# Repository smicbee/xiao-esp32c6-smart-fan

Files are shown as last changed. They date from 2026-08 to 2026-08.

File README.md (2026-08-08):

# XIAO ESP32C6 Smart Fan





A hardware-verified retrofit that turns a simple three-speed rechargeable desk fan into a Wi-Fi/Home Assistant device **without replacing its original motor, charger, protection circuit, or buttons**.

The controller emulates the original active-low Power and Speed buttons, measures the real motor rail to identify Off/Stage 1/Stage 2/Stage 3, and converges from the freshly measured physical state to the latest requested state. Rapid commands are serialized by a generation-based worker instead of trusting delayed UI state.

> **German documentation:** [docs/README.de.md](docs/README.de.md)

> **Status:** Working prototype · hardware-specific · not certified. Recalibrate and electrically verify every different fan/controller revision before enabling button outputs.

<p align="center">
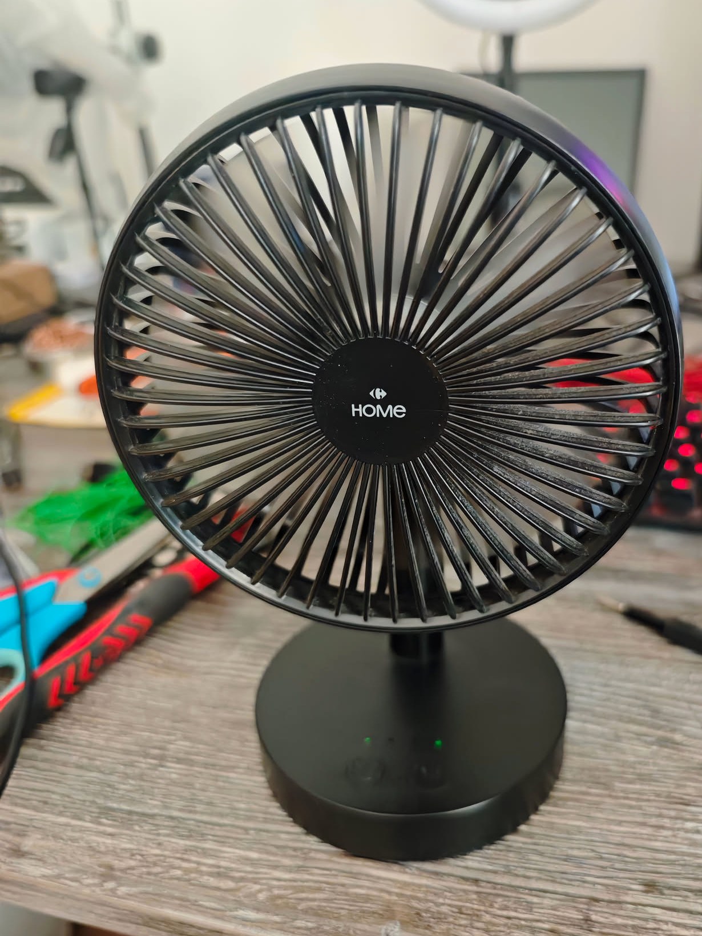
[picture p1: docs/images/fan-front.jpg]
Modified rechargeable desk fan
  
</p>

## What it can do

- Native encrypted ESPHome API and OTA updates over Wi-Fi.
- Home Assistant `fan` entity with three speeds.
- Original Power and Speed buttons remain functional.
- Active-low, 50 ms, open-drain button emulation; outputs are released afterward.
- Direct stage targeting without routinely power-cycling the fan:
  - Off → target: one Power pulse, then only the required Speed pulses.
  - Stage X → Stage Y: only the forward cyclic Speed pulses.
  - Running → Off: one Power pulse.
- Fresh motor-voltage sample before every controller pass; no dependency on delayed Home Assistant display state.
- Generation-based latest-target worker for sub-second command bursts.
- Stable motor-stage telemetry with median filtering, hysteresis, and five-sample confirmation.
- State-only feedback reconciliation: measured state can update Home Assistant but cannot generate a button pulse.
- Battery voltage and voltage-based state-of-charge estimate.
- Low-voltage protection: three readings below 3.05 V, deep sleep, 60 s wake checks, normal boot above 3.35 V.
- BMP280 temperature and pressure telemetry over SPI.
- Structured request/worker/ADC/GPIO/feedback logs plus reset reason, heap and maximum-loop-time diagnostics.

## Hardware

<p align="center">
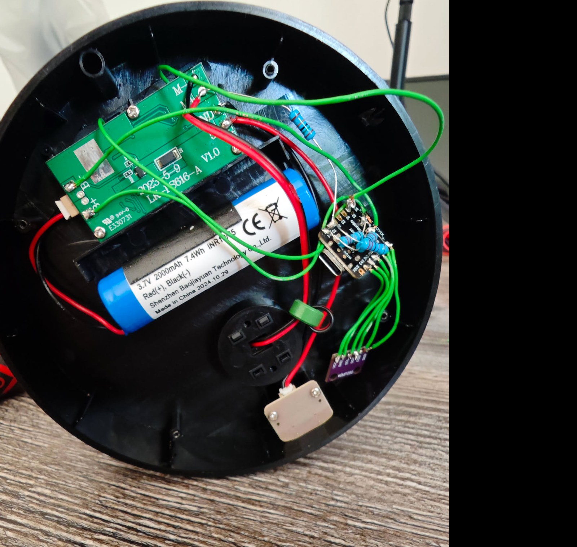
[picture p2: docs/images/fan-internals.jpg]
Fan internals and retrofit wiring
  
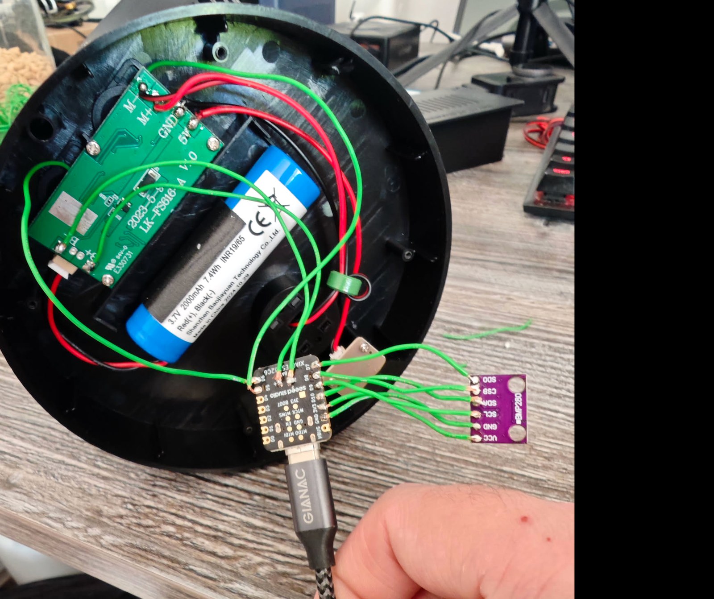
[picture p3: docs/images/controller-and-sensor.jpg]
XIAO ESP32C6 and BMP280 wiring
  
</p>

The prototype uses:

- Seeed Studio XIAO ESP32C6 (ESP32-C6FH4)
- BMP280 breakout (SPI)
- 150 kΩ + 22 kΩ motor-feedback divider
- 220 kΩ + 220 kΩ battery divider
- verified common ground between fan electronics and XIAO
- original 1-cell battery, motor controller, charger and protection electronics

See [hardware/BOM.csv](hardware/BOM.csv) and [docs/wiring.md](docs/wiring.md).

### Electrical schematic

XIAO ESP32C6 smart fan electrical schematic

The [editable KiCad 9 source](hardware/xiao-esp32c6-smart-fan.kicad_sch) shows the verified prototype topology: the XIAO only emulates the original Power/Speed buttons and measures divided-down voltages. It does not drive the motor directly and is not powered from the fan battery in the documented USB-powered prototype.

## Pin map

| XIAO pin | ESP32-C6 GPIO | Function |
|---|---:|---|
| D0 / A0 | GPIO0 | Battery ADC through 220 kΩ / 220 kΩ divider |
| D1 / A1 | GPIO1 | Motor rail ADC through 150 kΩ / 22 kΩ divider |
| D5 | GPIO23 | Original Speed button input, active-low/open-drain |
| D6 | GPIO16 | Original Power button input, active-low/open-drain |
| D7 | GPIO17 | BMP280 MISO / SDO |
| D8 | GPIO19 | BMP280 CSB |
| D9 | GPIO20 | BMP280 SCK / SCL |
| D10 | GPIO18 | BMP280 MOSI / SDA |
| 3V3 | — | BMP280 supply |
| GND | — | Common ground |

## Measured motor-voltage clusters

These values belong to the documented prototype and **must be recalibrated for another fan/controller**.

| Physical state | Reconstructed motor rail |
|---|---:|
| Off, no charger in one test | ~3.565 V |
| Off, USB charging | 4.636–4.683 V |
| Stage 1 | 4.941–4.980 V |
| Stage 2 | 6.513–6.536 V |
| Stage 3 | 7.912–7.960 V |

The charging Off cluster and Stage 1 are only about 0.27 V apart. The firmware therefore uses a midpoint for initial classification, Schmitt thresholds for subsequent transitions, ADC multisampling, median filtering and five stable samples. See [docs/calibration.md](docs/calibration.md).

## Control architecture

Controller architecture

Home Assistant supplies intent; the XIAO owns all GPIO actions:

1. `on_state` and `on_speed_set` store `requested_on`, `requested_stage` and increment `request_generation`.
2. A 250 ms dispatcher starts one single-owner worker if a generation is pending.
3. The worker force-updates the motor ADC and classifies the immediate 16-sample average.
4. It executes the minimum bounded pulse sequence from measured stage to requested stage.
5. It marks only the generation captured at worker start as handled. A newer request remains pending and gets another fresh physical read.
6. Slow filtered feedback later becomes authoritative for Home Assistant reconciliation, without touching the button outputs.

This design avoids the common `mode: restart` failure where a new request cancels a sequence after a physical pulse, and avoids relying on stale filtered/UI state.

## Quick start

### 1. Inspect and measure first

Do not assume another fan uses safe 3.3 V button signals or a ground-referenced motor rail.

- Disconnect power and identify Power, Speed, BAT+, BAT−, Motor+ and Motor−.
- Verify button-pad idle/pressed voltages and common ground with a multimeter.
- Confirm the selected motor low side remains at common ground in all states.
- Size dividers for the maximum credible voltage plus transient margin.
- First deploy voltage telemetry only and measure every state, both with and without charging.

### 2. Configure ESPHome secrets

```bash
cp esphome/secrets.example.yaml esphome/secrets.yaml
# edit esphome/secrets.yaml with your own values
```

### 3. Validate and commission over USB

```bash
python3.12 -m venv .venv
. .venv/bin/activate
pip install "esphome==2026.7.4"
esphome config esphome/ventilator-controller.yaml
esphome run esphome/ventilator-controller.yaml
```

The recommended workflow is **USB once, Wi-Fi/API/OTA immediately**. After the first successful boot and encrypted API verification, build and upload directly over the network:

```bash
esphome run esphome/ventilator-controller.yaml --device xiao-esp32c6-smart-fan.local
```

### 4. Add it to Home Assistant

ESPHome discovery normally offers the device automatically. Enter the API encryption key from your local `secrets.yaml`. Use the native three-speed fan entity; no custom stage buttons are required. See [docs/home-assistant.md](docs/home-assistant.md).

## Verified prototype behavior

Real hardware tests included:

- individual `3 → 1`, `1 → 2`, `2 → 3`, and final Off transitions;
- rapid `Stage 1 → Stage 3 → Off` requests within 0.99 s, ending physically Off;
- rapid `Off → Stage 1 → Stage 2 → Stage 3` requests within 1.08 s, ending physically at Stage 3 (~7.92 V);
- feedback reconciliation from the original hardware button;
- USB charging while distinguishing Off from Stage 1;
- encrypted Native API and OTA reconnect;
- firmware 1.5.6 diagnostic logging on real `Off → Stage 1 → Off` transitions;
- safe final state after tests.

The exact evidence boundary—including which firmware was exercised on hardware and which checks remain open—is documented in [docs/testing.md](docs/testing.md).

## Photos

<p align="center">
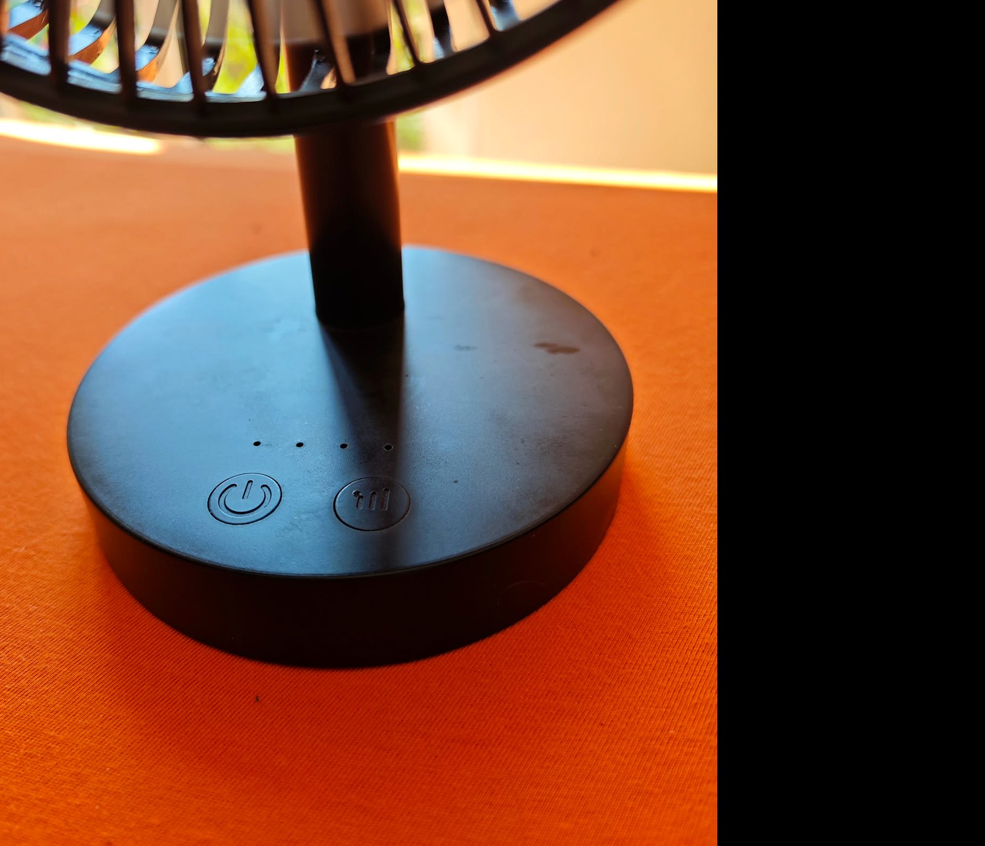
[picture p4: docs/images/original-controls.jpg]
Original power and speed controls
  
  Opened fan base
</p>

## Safety and limitations

- Modifying a Li-ion-powered appliance can cause fire, electric shock, battery damage or controller failure.
- Treat flashing, rebooting, restored state and Home Assistant commands as possible motor-start events during commissioning. Keep hands and loose objects clear and disconnect the motor while validating an unknown interface where practical.
- The XIAO is **not** the battery charger or BMS. The original electronics remain responsible for charging and protection.
- The photographed prototype was powered/programmed through USB during development. Do not connect the cell directly to XIAO 3V3/5V.
- Never connect Motor+ directly to an ADC pin.
- Direct GPIO button emulation is appropriate only after proving compatible voltage levels and common ground. Otherwise use a transistor, MOSFET or optocoupler interface.
- Motor outputs may be PWM even when a multimeter shows a stable average.
- Voltage-derived battery percentage is an estimate affected by load, chemistry, temperature and calibration.
- The narrow charging-Off/Stage-1 gap may not remain valid with another charger, cable, battery or fan revision.
- The low-voltage thresholds supplement; they do not replace the cell protection circuit.
- Keep the ESPHome API and OTA service on a trusted local network or VPN; do not expose ports 6053/3232 directly to the Internet.

## Repository layout

```text
esphome/                 ESPHome firmware and secrets template
hardware/                BOM / parts list
docs/diagrams/           public wiring and architecture drawings
docs/                    wiring, calibration, HA setup and German documentation
docs/images/             project photographs
tools/                   optional serial bring-up helper
.github/workflows/       ESPHome validation/compile CI
```

## License

Software, diagrams and documentation are released under the [MIT License](LICENSE). Product names and trademarks belong to their respective owners.

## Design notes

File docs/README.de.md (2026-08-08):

# XIAO ESP32C6 Smart Fan – deutsche Projektdokumentation

Dieses Projekt rüstet einen einfachen dreistufigen Akku-Tischventilator mit WLAN und Home Assistant nach. Die originale Motorsteuerung, Ladeelektronik, Zellschutzschaltung und die beiden Taster bleiben erhalten. Ein Seeed Studio XIAO ESP32C6 emuliert nur die aktiven Low-Taster und misst zusätzlich Motor- und Akkuspannung.

Umgebauter Ventilator

## Funktionsumfang

- verschlüsselte ESPHome Native API und OTA
- native dreistufige Home-Assistant-Fan-Entity
- weiterhin nutzbare Originaltaster
- 50-ms-Impulse auf Power und Speed, anschließend elektrische Freigabe
- gezielte Stufenwechsel ohne routinemäßiges Aus-/Ein-Reset
- echte Stufenerkennung über Motor+ und Spannungsteiler an D1/GPIO1
- frische Istmessung vor jedem Controllerdurchlauf
- generationenbasierter Worker für schnelle Folgebefehle
- hardwarebasierte, impulsfreie Korrektur der HA-Anzeige
- BMP280 für Temperatur und Luftdruck
- Akkuspannung und geschätzter Ladezustand
- Unterspannungs-Deep-Sleep mit 60-s-Prüfintervall

## Wesentliche Architekturentscheidung

Home Assistant ist nur Sollwertgeber. Der Home-Assistant-Anzeigestand wird niemals als physischer Istzustand verwendet. Jede noch offene Sollanforderung führt zu einem neuen D1-ADC-Snapshot. Daraus berechnet der XIAO die minimale Aktion:

- **Aus → Zielstufe:** Power-Impuls, dann nötige Speed-Impulse
- **Stufe X → Stufe Y:** nur zyklisch nötige Speed-Impulse
- **Laufend → Aus:** genau ein Power-Impuls

Während eines 50-ms-Impulses besitzt genau ein Worker die Ausgänge. Neue Befehle erhöhen eine Generation und bleiben offen. Nach Abschluss erfolgt eine neue Istmessung für den neuesten Sollwert. Die langsame gefilterte Rückmeldung darf Home Assistant aktualisieren, aber niemals selbst einen Tasterimpuls auslösen.

## Hardware und Verdrahtung

Siehe [wiring.md](wiring.md) und [../hardware/BOM.csv](../hardware/BOM.csv).

Verdrahtungsplan

### Spannungsteiler

Motorfeedback:

```text
Motor+ ── 150 kΩ ──┬── D1 / GPIO1
                    │
                   22 kΩ
                    │
GND / Motor− ───────┴── GND
```

Akkumessung:

```text
BAT+ ── 220 kΩ ──┬── D0 / GPIO0
                  │
                 220 kΩ
                  │
BAT− / GND ───────┴── GND
```

Die Motor-Rückrechnung verwendet `(150k + 22k) / 22k ≈ 7,818`. Motor+ darf niemals direkt mit D1 verbunden werden.

## Gemessene Spannungen

| Zustand | Motorspannung |
|---|---:|
| Aus ohne USB in einer Messreihe | ca. 3,565 V |
| Aus während USB-Ladung | 4,636–4,683 V |
| Stufe 1 | 4,941–4,980 V |
| Stufe 2 | 6,513–6,536 V |
| Stufe 3 | 7,912–7,960 V |

Die Trennung zwischen USB-Aus und Stufe 1 ist knapp. Deshalb müssen andere Geräte zunächst passiv vermessen und neu kalibriert werden. Details: [calibration.md](calibration.md).

## Inbetriebnahme

1. Spannungen, gemeinsame Masse und Tasterpegel am eigenen Gerät messen.
2. Zunächst nur passive Telemetrie aktivieren und alle Zustände mit/ohne Ladegerät erfassen.
3. `esphome/secrets.example.yaml` nach `esphome/secrets.yaml` kopieren und eigene Werte einsetzen.
4. Einmalig per USB flashen.
5. WLAN, verschlüsselte API und OTA sofort real prüfen.
6. Danach direkt über WLAN weiterentwickeln; USB nur für Recovery/Seriell verwenden.
7. In Home Assistant die native Fan-Entity verwenden. Zusätzliche Stufenbuttons sind nicht nötig.

## Grenzen und Sicherheit

- Li-Ion-Geräte nur mit geeigneter Messtechnik und Brandschutz öffnen/modifizieren.
- Originale Lade- und Schutzschaltung nicht ersetzen oder umgehen.
- XIAO nicht direkt aus der Zelle an 3V3/5V speisen.
- Bei Tasterspannungen oberhalb der GPIO-Grenzen eine Transistor-/MOSFET-/Optokopplerstufe verwenden.
- Die vorhandenen Schwellwerte gelten nur für den vermessenen Prototyp.
- Akkuprozent ist eine Spannungsschätzung, keine Coulomb-Zählung.
- Deep Sleep ersetzt nicht den Hardware-Zellschutz.

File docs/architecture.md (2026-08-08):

# Control architecture

Architecture

## Why optimistic control was not enough

The fan's original controls are toggle/cycle buttons. Home Assistant state can lag, an original hardware-button press bypasses Home Assistant, and the motor-voltage telemetry intentionally waits for stable samples. A naïve `mode: restart` script can be interrupted after a real pulse but before its software state is updated.

## Latest-target generation worker

The firmware keeps three monotonically compared values:

- `request_generation`: incremented by user state/speed events;
- `processing_generation`: captured at the beginning of a worker pass;
- `handled_generation`: advanced only to the captured generation after a valid pass.

A request arriving during an active pass therefore remains pending. The next pass obtains a new D1 measurement instead of continuing an obsolete plan.

## Two measurement paths

- **Command snapshot:** existing ADC is force-updated; `on_raw_value` captures the 16-sample average before temporal median filtering.
- **Public/authoritative telemetry:** multiply + five-value median + hysteresis + five consecutive classifications.

Hardware reconciliation is guarded so publication cannot become a command.

## Low-battery state flow

```text
Battery ADC every 5 s
        │
        ├─ value ≥ 3.10 V → reset consecutive-low counter
        │
        └─ value < 3.05 V → increment counter
                                  │
                             three samples
                                  │
                  stop command worker; enable feedback guard
                                  │
                  publish Fan=Off without a button pulse
                                  │
                         enter deep sleep for 60 s
                                  │
                         timer wake and fresh ADC read
                                  │
                 < 3.35 V ───────┴─────── ≥ 3.35 V
                 sleep again                normal boot
```

This firmware path supplements the original cell protection. It is not a charger, BMS or continuously awake undervoltage supervisor.

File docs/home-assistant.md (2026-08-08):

# Home Assistant

ESPHome exposes a native three-speed `fan` entity plus:

- motor voltage;
- confirmed hardware stage 0–3;
- hardware running state;
- battery voltage;
- estimated battery percentage;
- temperature and pressure;
- Wi-Fi diagnostics and uptime.

Use the standard Home Assistant fan tile/card with its native speed control. No helper buttons or stage scripts are required. The frontend sends intent; the controller determines the physical transition from a fresh hardware measurement.

The API is encrypted. Keep the Noise PSK and OTA password only in local `secrets.yaml`. Do not place them in dashboards, automations or Git.

## Optional stale-telemetry recovery

ESPHome enables the ESP-IDF Task Watchdog for the loop task. That watchdog catches a task which stops yielding, but it cannot prove that every ESPHome scheduler component continues to execute. A device can therefore remain reachable while sensor intervals and actuator automations have stopped.

The automation below detects that narrower failure mode through the uptime entity. It deliberately does **not** restart a device which is `unavailable`, because that may be intentional battery-protection deep sleep. It requests one controller restart after three stale minutes, waits for fresh telemetry, creates a persistent notification only if recovery fails, and then remains busy for ten minutes to prevent a reboot loop.

Entity IDs are installation-specific; select the uptime sensor and ESPHome restart button created for your device.

```yaml
alias: Fan Controller – Telemetry Watchdog
description: Recover an API-reachable controller whose ESPHome scheduler stopped publishing.
mode: single
max_exceeded: silent
triggers:
  - trigger: time_pattern
    minutes: /1
conditions:
  - condition: template
    value_template: >
      {% set s = states.sensor.xiao_esp32c6_smart_fan_uptime %}
      {{ s is not none
         and s.state not in ['unknown', 'unavailable', 'none']
         and states('button.xiao_esp32c6_smart_fan_restart') != 'unavailable'
         and (as_timestamp(now()) - as_timestamp(s.last_updated)) > 180 }}
actions:
  - variables:
      watchdog_before_updated: >
        {{ as_timestamp(states.sensor.xiao_esp32c6_smart_fan_uptime.last_updated) }}
  - action: button.press
    target:
      entity_id: button.xiao_esp32c6_smart_fan_restart
  - wait_template: >
      {% set s = states.sensor.xiao_esp32c6_smart_fan_uptime %}
      {{ s is not none
         and s.state not in ['unknown', 'unavailable', 'none']
         and as_timestamp(s.last_updated) > (watchdog_before_updated | float(0)) }}
    timeout: 00:01:30
    continue_on_timeout: true
  - choose:
      - conditions:
          - condition: template
            value_template: '{{ not wait.completed }}'
        sequence:
          - action: persistent_notification.create
            data:
              notification_id: fan_controller_watchdog_failed
              title: Fan controller did not recover
              message: >
                The telemetry watchdog requested a controller restart but received
                no fresh uptime value within 90 seconds. Check power and ESPHome.
  - delay: 00:10:00
```

Do not use this pattern for a controller whose boot path can actuate hardware. Verify first that reboot leaves all button outputs released and does not restore an unsafe command.

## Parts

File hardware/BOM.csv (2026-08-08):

Reference | Quantity | Part | Value or model | Notes
MCU1 | 1 | Microcontroller | Seeed Studio XIAO ESP32C6 | ESP32-C6FH4 prototype
SENS1 | 1 | Pressure/temperature sensor | BMP280 breakout | 3.3 V SPI mode
R1 | 1 | Resistor | 150 kOhm | Motor feedback top resistor
R2 | 1 | Resistor | 22 kOhm | Motor feedback bottom resistor
R3-R4 | 2 | Resistor | 220 kOhm | Battery 1:2 divider
C1 | 0-1 | Capacitor | 100 nF | Optional D1-to-GND noise/PWM filter; not fitted in prototype
WIRE | as needed | Insulated hookup wire |  | Keep wiring strain-relieved and clear of moving parts
FAN1 | 1 | Rechargeable three-speed desk fan |  | Original motor/controller/charger/protection retained

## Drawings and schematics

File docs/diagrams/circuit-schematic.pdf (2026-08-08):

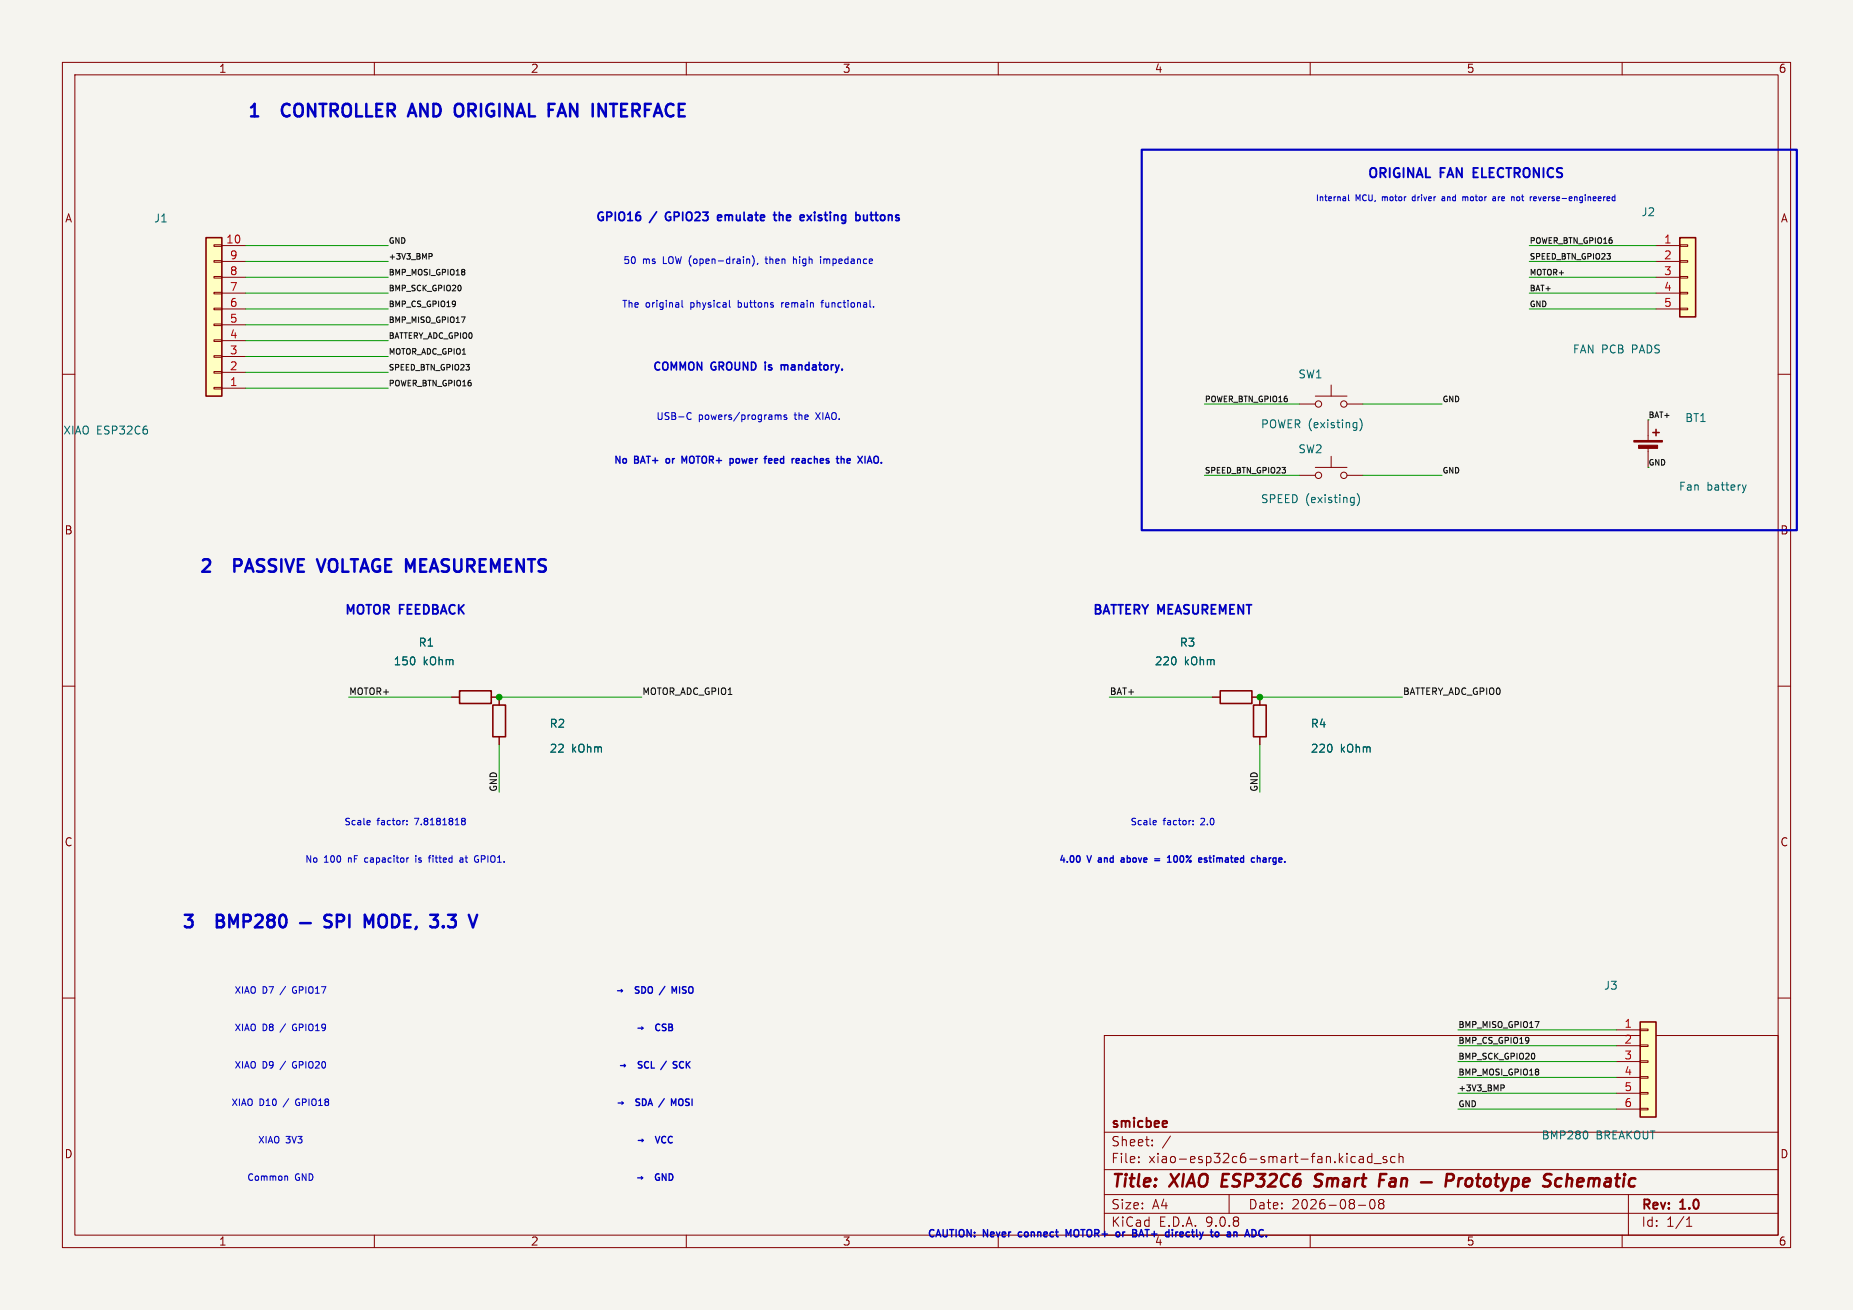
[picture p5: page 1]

1 CONTROLLER AND ORIGINAL FAN INTERFACE

4.00 V and above = 100% estimated charge. BATTERY MEASUREMENT

þÿ!’ SDA / MOSI þÿ!’ SCL / SCK

File: xiao-esp32c6-smart-fan.kicad_sch Sheet: / smicbee

Id: 1/1 Title: XIAO ESP32C6 Smart Fan þÿ Prototype Schematic

CAUTION: Never connect MOTOR+ or BAT+ directly to an ADC.

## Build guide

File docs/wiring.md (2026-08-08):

# Wiring

## Electrical schematic

Electrical schematic

The editable [KiCad 9 schematic](../hardware/xiao-esp32c6-smart-fan.kicad_sch) is the design source. A [PDF version](diagrams/circuit-schematic.pdf) is available for printing and offline reference.

This schematic separates the original fan electronics from the retrofit. The XIAO emulates the existing buttons and measures the motor and battery rails through voltage dividers; it does **not** drive the motor directly. The documented prototype powers/programs the XIAO through USB and has no fan-battery power feed into XIAO 3V3 or 5V.

## Simplified wiring overview

Complete wiring diagram

## Button emulation

The original fan controller exposes separate Power and Speed push-button signals. In the measured prototype, pressing either button shorts its signal to common ground. D6/GPIO16 and D5/GPIO23 emulate this with inverted open-drain outputs for 50 ms.

Before reproducing this:

1. Measure idle and pressed voltage at both button pads.
2. Prove that fan ground and XIAO ground may be connected.
3. Confirm that no button signal can exceed ESP32-C6 GPIO limits.
4. Use a transistor/MOSFET/opto-isolated interface if compatibility is uncertain.

## Motor feedback divider

`Motor+ → 150 kΩ → D1/GPIO1 → 22 kΩ → GND`

- Divider ratio: `22 / 172 ≈ 0.1279`
- Reconstruction factor: `172 / 22 ≈ 7.818`
- Thevenin resistance: `150 kΩ || 22 kΩ ≈ 19.2 kΩ`

A 100 nF capacitor from D1 to ground can improve PWM/noise averaging, but it was not fitted in the documented prototype. Software uses 16-sample ADC averaging and a five-value median.

## Battery divider

`BAT+ → 220 kΩ → D0/GPIO0 → 220 kΩ → GND`

This divides a one-cell battery voltage by two. The original fan electronics still charge and protect the cell.

## BMP280 SPI

| BMP280 | XIAO |
|---|---|
| VCC | 3V3 |
| GND | GND |
| SDO | D7 / GPIO17 (MISO) |
| CSB | D8 / GPIO19 |
| SCL | D9 / GPIO20 (SCK) |
| SDA | D10 / GPIO18 (MOSI) |

Breakout labels vary. Verify the module schematic and 3.3 V compatibility.

## Power topology

The development prototype shows the XIAO powered/programmed via USB. The fan battery is not connected directly to XIAO 3V3 or 5V. If a self-contained power supply is desired, design and verify a separate regulated supply and ensure that charging through two paths cannot occur.

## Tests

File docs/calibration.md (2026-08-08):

# Calibration and thresholds

Do not copy the included thresholds blindly to another fan.

## Measurement procedure

1. Deploy the motor-voltage sensor as telemetry only.
2. Record the ADC midpoint and reconstructed motor rail with the fan Off and at every speed.
3. Repeat with no charger and while charging.
4. Repeat at low, medium and high cell voltage when practical.
5. Capture ranges, not single readings; check for PWM with an oscilloscope if available.
6. Place initial thresholds at gaps between non-overlapping clusters.
7. Add hysteresis and stable-sample confirmation.

## Prototype thresholds

Initial cluster midpoints used by the immediate command path:

- Off / Stage 1: 4.804 V
- Stage 1 / Stage 2: 5.727 V
- Stage 2 / Stage 3: 7.213 V

The slow telemetry classifier uses state-dependent Schmitt thresholds. In particular, it enters Stage 1 from Off at 4.84 V and returns to Off below 4.77 V.

## Prototype battery estimate

The documented charger repeatedly leveled off at approximately **4.00 V** rather than 4.20 V. Firmware 1.5.8 therefore treats 4.00 V and above as 100% for this prototype. The upper calibration points are:

| Battery voltage | Estimated level |
|---:|---:|
| 3.90 V | 65% |
| 3.95 V | 82.5% |
| 4.00 V or above | 100% |

The low-voltage/deep-sleep thresholds are unchanged. This remains a voltage-derived estimate affected by motor load, charging, temperature, cell chemistry and ADC calibration; the raw battery-voltage sensor remains authoritative evidence.

## Failure policy

If values enter an ambiguous gap, drift toward a threshold, or supported operating modes overlap, keep the state unknown/telemetry-only. Never emit a blind toggle sequence from an unknown stage.

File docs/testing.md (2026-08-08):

# Test evidence and current boundary

This document separates real prototype evidence from configuration/build-only checks. It intentionally does not turn an untested assumption into a compatibility claim.

## Real hardware evidence

The prototype was exercised with firmware 1.5.4 and later 1.5.6 on a Seeed Studio XIAO ESP32C6 connected to the documented fan electronics.

| Test | Observed result |
|---|---|
| Power button emulation | 50 ms active-low/open-drain pulse started the stopped fan at Stage 1 |
| Speed button emulation | One pulse advanced Stage 1 → Stage 2; outputs released afterward |
| Power-off emulation | One Power pulse stopped the running fan |
| Targeted stages | `3 → 1`, `1 → 2`, `2 → 3` reached the expected measured clusters without routine power reset |
| Rapid latest-target burst | `Stage 1 → Stage 3 → Off` within 0.99 s ended physically Off |
| Rapid speed burst | `Off → Stage 1 → Stage 2 → Stage 3` within 1.08 s ended at Stage 3, about 7.92 V |
| Hardware feedback | Original-button changes were reflected back into the ESPHome/Home Assistant fan state without generating a new button pulse |
| Charging state | Off during USB charging (4.636–4.683 V) remained distinguishable from Stage 1 (4.941–4.980 V) in the tested setup |
| Connectivity | Encrypted ESPHome Native API reconnect and OTA update succeeded |

Measured running clusters were approximately 4.94–4.98 V, 6.51–6.54 V and 7.91–7.96 V for Stages 1–3.

## Firmware 1.5.5 verification history

Firmware 1.5.5 adds a feedback guard to the low-battery sleep path and removes a prototype-only migration. The public configuration was:

- validated locally with ESPHome 2026.6.5;
- fully compiled locally for ESP32-C6;
- fully validated and compiled again in GitHub Actions.

At initial publication, 1.5.5 had **not** yet been installed and exercised on the physical prototype. The real command-burst evidence above therefore belongs to 1.5.4; the relevant worker logic is otherwise unchanged.

## Firmware 1.5.6 diagnostic verification

Firmware 1.5.6 was validated and fully compiled locally with ESPHome 2026.7.4 / ESP-IDF 5.5.5, then installed over encrypted LAN OTA on the real prototype. The live device reported configuration hash `0xccb9c359`.

The diagnostic release adds structured event logs for:

- incoming state/speed requests and request generations;
- worker start/end and freshly classified motor voltage;
- start and end of every 50 ms Power/Speed pulse;
- stable physical-feedback changes and UI synchronization;
- low-battery samples, recovery and deep-sleep entry;
- boot/reset reason, heap metrics and maximum main-loop time.

A persistent encrypted Native API collector captured a real `Off → Stage 1 → Off` test. Both directions logged request, fresh ADC classification, pulse start/end, worker completion and delayed hardware-feedback confirmation. Physical evidence was Stage 1 at approximately 4.95 V and final Off at approximately 4.66 V. The controller remained Off after the test.

The built-in ESP-IDF task watchdog remains enabled with its ESPHome default timeout. The external stale-telemetry automation documented in [home-assistant.md](home-assistant.md) is still useful because a scheduler/component stall can leave network tasks alive without necessarily starving the outer watched task.

## Firmware 1.5.7 Off-to-Stage-3 regression test

Firmware 1.5.7 fixes a dynamic-repeat-count defect found through the 1.5.6 event logs. ESPHome reevaluates a lambda-based `repeat.count` after every pass. Because the earlier expression derived the remaining count from an estimate that advanced after each pulse, a direct `Off → Stage 3` request stopped after one Speed pulse and physically reached only Stage 2.

The worker now snapshots the requested state/stage and the complete Speed-pulse count at worker start. A newer request remains pending as a later generation instead of changing the running sequence.

The fix was validated and compiled with ESPHome 2026.7.4 / ESP-IDF 5.5.5, installed over encrypted LAN OTA, and tested on the physical prototype:

- initial state Off / hardware stage 0 at approximately 4.66 V;
- direct Home Assistant request to Stage 3;
- one complete Power pulse followed by exactly two complete Speed pulses;
- worker estimate and filtered hardware feedback both reached Stage 3;
- measured motor rail approximately 7.912 V;
- final Power-off test returned to hardware stage 0 at approximately 4.69 V.

## Firmware 1.5.8 battery-full calibration

Firmware 1.5.8 changes only the battery-percentage calibration and the matching boot-version log. The observed charger plateau of approximately 4.00 V is now the 100% endpoint; low-voltage and deep-sleep protection thresholds are unchanged.

The firmware was validated and fully compiled with ESPHome 2026.7.4 / ESP-IDF 5.5.5, installed over encrypted LAN OTA and verified through Home Assistant. The live prototype reported approximately 4.015 V and an estimated level of 100%. The fan was intentionally returned to Stage 3 after verification.

## Checks still required for another build

- Measure button idle/pressed levels and prove common ground before connecting GPIOs.
- Repeat motor-voltage clusters with the actual charger, cable, battery state and temperature range.
- Calibrate both ADC dividers against a trusted multimeter.
- Check for PWM/ripple with an oscilloscope when thresholds are narrow.
- Perform a controlled full undervoltage/deep-sleep/recovery test.
- Verify enclosure insulation, strain relief, clearance from moving parts and thermal behavior.

Unknown or overlapping voltage clusters must remain telemetry-only; never replace missing evidence with blind toggle sequences.

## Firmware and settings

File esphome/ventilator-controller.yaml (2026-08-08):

esphome:
  name: xiao-esp32c6-smart-fan
  friendly_name: XIAO Smart Fan
  comment: Three-speed battery fan retrofit with physical feedback
  project:
    name: smicbee.xiao_esp32c6_smart_fan
    version: "1.5.8"
  # On every boot (including a timer wake-up), measure before Wi-Fi starts.
  # A still-empty battery immediately returns to deep sleep; charging above
  # the recovery threshold allows a normal boot.
  on_boot:
    - priority: 500
      then:
        - lambda: |-
            ESP_LOGI("fan_diag", "BOOT firmware=1.5.8");
        - component.update: battery_voltage
        - if:
            condition:
              lambda: return id(battery_voltage_fast) < 3.35f;
            then:
              - script.execute: enter_low_battery_sleep

esp32:
  board: seeed_xiao_esp32c6
  variant: esp32c6
  framework:
    type: esp-idf

logger:
  level: DEBUG

debug:
  update_interval: 60s

api:
  encryption:
    key: !secret api_encryption_key

ota:
  - platform: esphome
    password: !secret ota_password

wifi:
  ssid: !secret wifi_ssid
  password: !secret wifi_password
  power_save_mode: none
  reboot_timeout: 10min

deep_sleep:
  id: low_battery_deep_sleep
  sleep_duration: 60s

mdns:

spi:
  clk_pin: GPIO20   # D9 / BMP280 SCL
  mosi_pin: GPIO18  # D10 / BMP280 SDA
  miso_pin: GPIO17  # D7 / BMP280 SDO

output:
  - platform: gpio
    id: fan_power_pulse
    pin:
      number: GPIO16  # D6
      inverted: true
      mode:
        output: true
        open_drain: true

  - platform: gpio
    id: fan_speed_pulse
    pin:
      number: GPIO23  # D5
      inverted: true
      mode:
        output: true
        open_drain: true

globals:
  - id: fan_physical_on
    type: bool
    restore_value: true
    initial_value: "false"

  - id: battery_voltage_fast
    type: float
    restore_value: false
    initial_value: "NAN"

  - id: low_voltage_samples
    type: uint8_t
    restore_value: false
    initial_value: "0"


  - id: hardware_sync_active
    type: bool
    restore_value: false
    initial_value: "false"

  - id: hardware_fan_stage_value
    type: uint8_t
    restore_value: false
    initial_value: "255"

  - id: hardware_stage_candidate
    type: uint8_t
    restore_value: false
    initial_value: "255"

  - id: hardware_stage_candidate_samples
    type: uint8_t
    restore_value: false
    initial_value: "0"

  # Immediate command-side estimate. Unlike the filtered hardware value this
  # advances after every completed button pulse, allowing rapid commands to be
  # serialized without waiting several seconds for ADC confirmation.
  - id: control_stage_estimate
    type: uint8_t
    restore_value: false
    initial_value: "255"

  - id: control_feedback_hold_until
    type: uint32_t
    restore_value: false
    initial_value: "0"

  - id: motor_voltage_fast
    type: float
    restore_value: false
    initial_value: "NAN"

  - id: requested_fan_on
    type: bool
    restore_value: false
    initial_value: "false"

  - id: requested_fan_stage
    type: uint8_t
    restore_value: false
    initial_value: "1"

  - id: request_generation
    type: uint32_t
    restore_value: false
    initial_value: "0"

  - id: processing_generation
    type: uint32_t
    restore_value: false
    initial_value: "0"

  - id: processing_requested_fan_on
    type: bool
    restore_value: false
    initial_value: "false"

  - id: processing_requested_fan_stage
    type: uint8_t
    restore_value: false
    initial_value: "1"

  - id: processing_speed_pulse_count
    type: uint8_t
    restore_value: false
    initial_value: "0"

  - id: handled_generation
    type: uint32_t
    restore_value: false
    initial_value: "0"
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

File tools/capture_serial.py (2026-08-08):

#!/usr/bin/env python3
"""Capture ESPHome serial logs without asserting DTR/RTS."""
import argparse
import time
import serial

parser = argparse.ArgumentParser()
parser.add_argument("port", help="Serial port, for example /dev/ttyACM0 or COM3")
parser.add_argument("--seconds", type=float, default=30.0)
args = parser.parse_args()

ser = serial.Serial()
ser.port = args.port
ser.baudrate = 115200
ser.timeout = 0.25
ser.dtr = False
ser.rts = False
ser.open()
try:
    end = time.monotonic() + args.seconds
    while time.monotonic() < end:
        raw = ser.readline()
        if raw:
            print(raw.decode("utf-8", errors="replace").rstrip())
finally:
    ser.close()

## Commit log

2026-08-08 Initial public release of XIAO ESP32C6 smart fan
    [BOM.csv, ventilator-controller.yaml]
2026-08-08 Document test boundary and low-battery state flow
2026-08-08 Add persistent fan diagnostics in firmware 1.5.6
    [ventilator-controller.yaml]
2026-08-08 Fix direct off-to-stage-three transition
    [ventilator-controller.yaml]
2026-08-08 Add electrical schematic to documentation
2026-08-08 Redraw schematic with deterministic layout
2026-08-08 Calibrate full battery level at four volts
    [ventilator-controller.yaml]
2026-08-08 Replace generated diagram with KiCad schematic
    [xiao-esp32c6-smart-fan.kicad_sch]
2026-08-08 Improve schematic dark-mode rendering and public copy

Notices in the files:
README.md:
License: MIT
